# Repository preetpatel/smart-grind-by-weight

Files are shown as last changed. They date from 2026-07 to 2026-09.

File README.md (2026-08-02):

# Smart Grind-by-Weight

> **This is a fork of [jaapp/smart-grind-by-weight](https://github.com/jaapp/smart-grind-by-weight).**
> The original hardware design, firmware, and grinding algorithm are the work of **[Jaap (@jaapp)](https://github.com/jaapp)**.
> This fork is maintained by [@preetpatel](https://github.com/preetpatel) and has diverged since February 2026 —
> see [What's different in this fork](#-whats-different-in-this-fork).
> **Issues and support for this fork belong here, not upstream.**

**Turn any grinder into a precision smart grind-by-weight system**

<table>
<tr>
<td width="50%">

https://github.com/user-attachments/assets/e20ce3e2-417e-4a3b-bb48-05591fce9418

</td>
<td width="50%">

[Smart Grind-by-Weight Modification](media/smart-grind-by-weight-render.PNG)

</td>
</tr>
</table>

> **⚠️ Experimental Mod - Buyer Beware!**
> This is a **grinder modification project** that requires technical skill to build and may have rough edges. **Build at your own risk!**

The Smart Grind-by-Weight is a user-friendly, touch interface-driven, highly accurate open source grinder modification that transforms any grinder (with an accessible motor relay) into an intelligent grind-by-weight system. It was originally developed by Jaap for the Eureka Mignon Specialita, and can be adapted for other grinders.

**The concept is simple:** Perform a "brain swap" on your grinder. Replace the original controller with an ESP32-S3 controller and add a precision load cell to the mix.

**Upgrade cost:** €30-40 in parts
**Target accuracy:** ±0.03g tolerance
**No regrets:** No permanent modifications, and original grind-by-time mode is also available

---

## ✨ Features

- **User-friendly interface** with 3 profiles: Single, Double, Custom
- **Beautiful display** with simple graphics or detailed charts (easily switchable)
- **High accuracy**: ±0.03g error tolerance
- **Zero-shot learning**: Algorithm adapts instantly to any grind size, bean setting, humidity etc. without manual tuning
- **Original timed run preserved** – there is a setting to enable the original Grind-By-Time mode
- **BLE OTA updates** for firmware
- **Advanced analytics** — full in-browser dashboard over Web Bluetooth, plus local Streamlit tooling
- **On-device diagnostics** for calibration, load cell wiring, and mechanical instability faults
- **For Eureka**: No permanent modifications needed - just swap the screen and add 3D printed parts

---

## 🧠 Intelligent Grinding Algorithm

The predictive grinding system uses a zero-shot learning approach that adapts to any conditions:

```mermaid
flowchart LR
  start((Start Grind)) --> T[TARING]
  T --> E[PREDICTIVE<br/>learn latency & flow_rate<br/>compute motor_stop_target_weight]
  E --> S[SETTLING]
  S --> P[PULSE<br/>bounded pulse using effective_flow_rate]
  P -->|abs_error <= tolerance OR error < 0 OR pulses >= max| C[COMPLETED]
  P -->|needs more| S
```

**Key Innovation:** The algorithm learns grind latency and flow rate in real-time, then uses predictive control to stop just before the target weight, followed by precision pulses to reach exact accuracy. No manual tuning required.

---

## 🔀 What's different in this fork

This fork tracks upstream's hardware design and core algorithm, and adds reliability, diagnostics, and tooling work:

**Accuracy & motor control**
- Exact, deterministic motor pulses; pulse completion detected without polling the RMT driver
- 0.1s minimum pulse floor and preserved flow/calibration accuracy across grinds
- Tare and calibration failures now surface to the user instead of failing silently
- Correct auto-tune cancellation and failure reporting

**Diagnostics & device health**
- `LOAD_CELL_SATURATED` detection — catches A+/A- load cell wiring faults and blocks weight-mode grinds
- Internal and PSRAM heap census at startup and in the heartbeat, reported over BLE
- Per-task stack headroom in task heartbeats
- `grinder.py analyze` pulls grind data, system info, and diagnostics over one BLE connection into a **Device Health** dashboard view

**Grinding UX**
- Post-completion top-up pulses in **weight** mode (previously time mode only), with live weight and arc updates

**Stability & performance**
- BLE stack survives Bluetooth toggles instead of wedging
- LVGL heap allocated from PSRAM rather than internal DRAM; reduced per-frame heap churn and a fixed style leak
- LVGL pinned to 9.3.0 to match `lv_conf.h`

**Tooling & hardware**
- Host-side C++ regression tests, run by the build tool and in CI
- Forward-shifted cup holder variant for 43 mm cup bases

Full history is in the [commit log](https://github.com/preetpatel/smart-grind-by-weight/commits/main) and [Releases](https://github.com/preetpatel/smart-grind-by-weight/releases).

---

## 🚀 Quick Start

### For Users - Using Pre-built Firmware

1. **Get the parts** - ESP32-S3 AMOLED display + HX711 + load cell (~€35 total) → See [Parts List](docs/DOC.md#-parts-list)
2. **3D print the mounting parts** - All STL files included, no supports needed → See [3D Printed Parts](docs/DOC.md#3d-printed-parts) | [Community Designs](docs/3D_PRINTS.md)
3. **Flash firmware & calibrate** - [Web Flasher](https://coffeegrinder.preetpatel.com) (Chrome/Edge desktop + Android only) or command line
4. **Follow the assembly video** - [Complete Eureka build process](https://youtu.be/-kfKjiwJsGM) (by Jaap, for the original build)

**Ready to build?** → See **[DOC.md](docs/DOC.md)** for complete build instructions, parts list, and usage guide.

---

### For Developers - Building from Source

If you want to modify the code or contribute, see **[DEVELOPMENT.md](docs/DEVELOPMENT.md)** for build instructions.

**Design Files:** The complete Fusion 360 design is available at `3d_files/smart-grind-by-weight. Eureka Mignon.f3z` for modification and adaptation to other grinder models.

---

## 📊 Analytics Dashboard

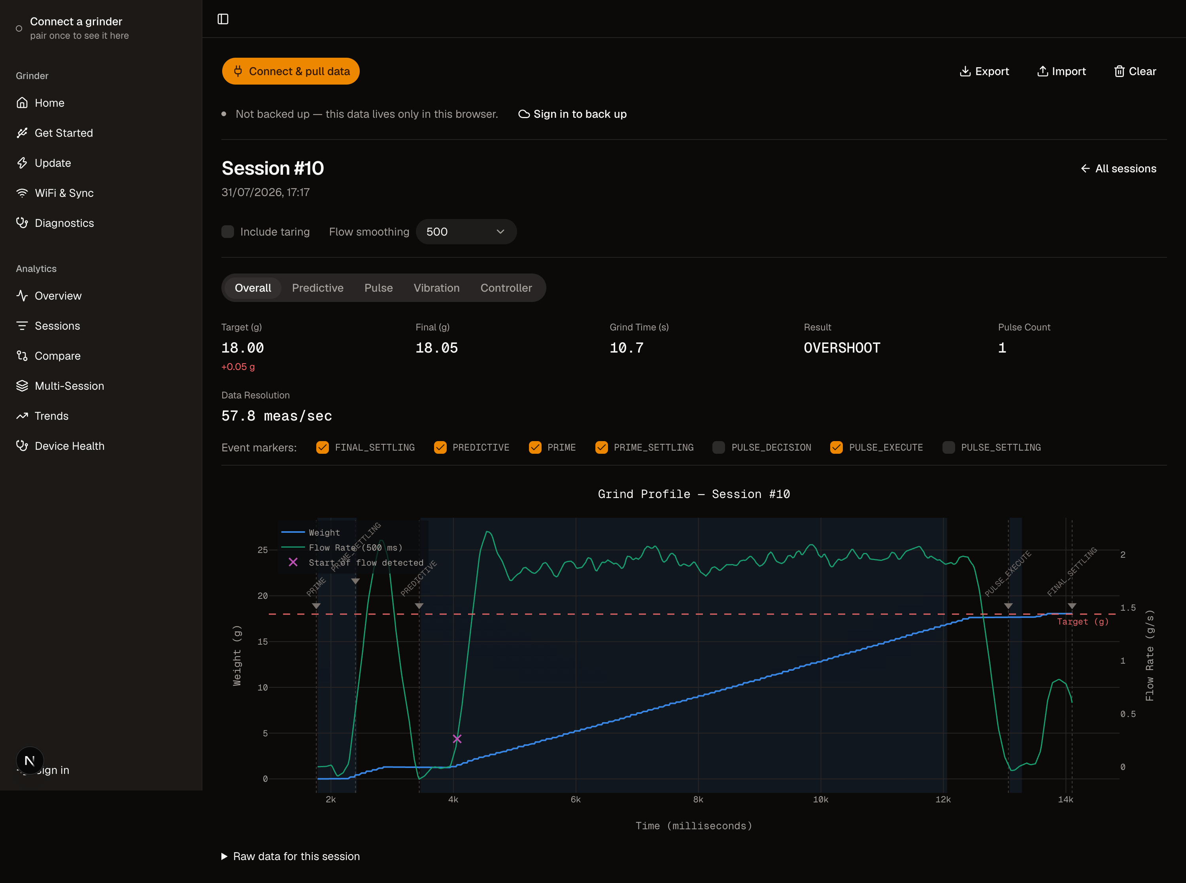
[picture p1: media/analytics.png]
Analytics Dashboard — single-session analysis
[](media/analytics.png)

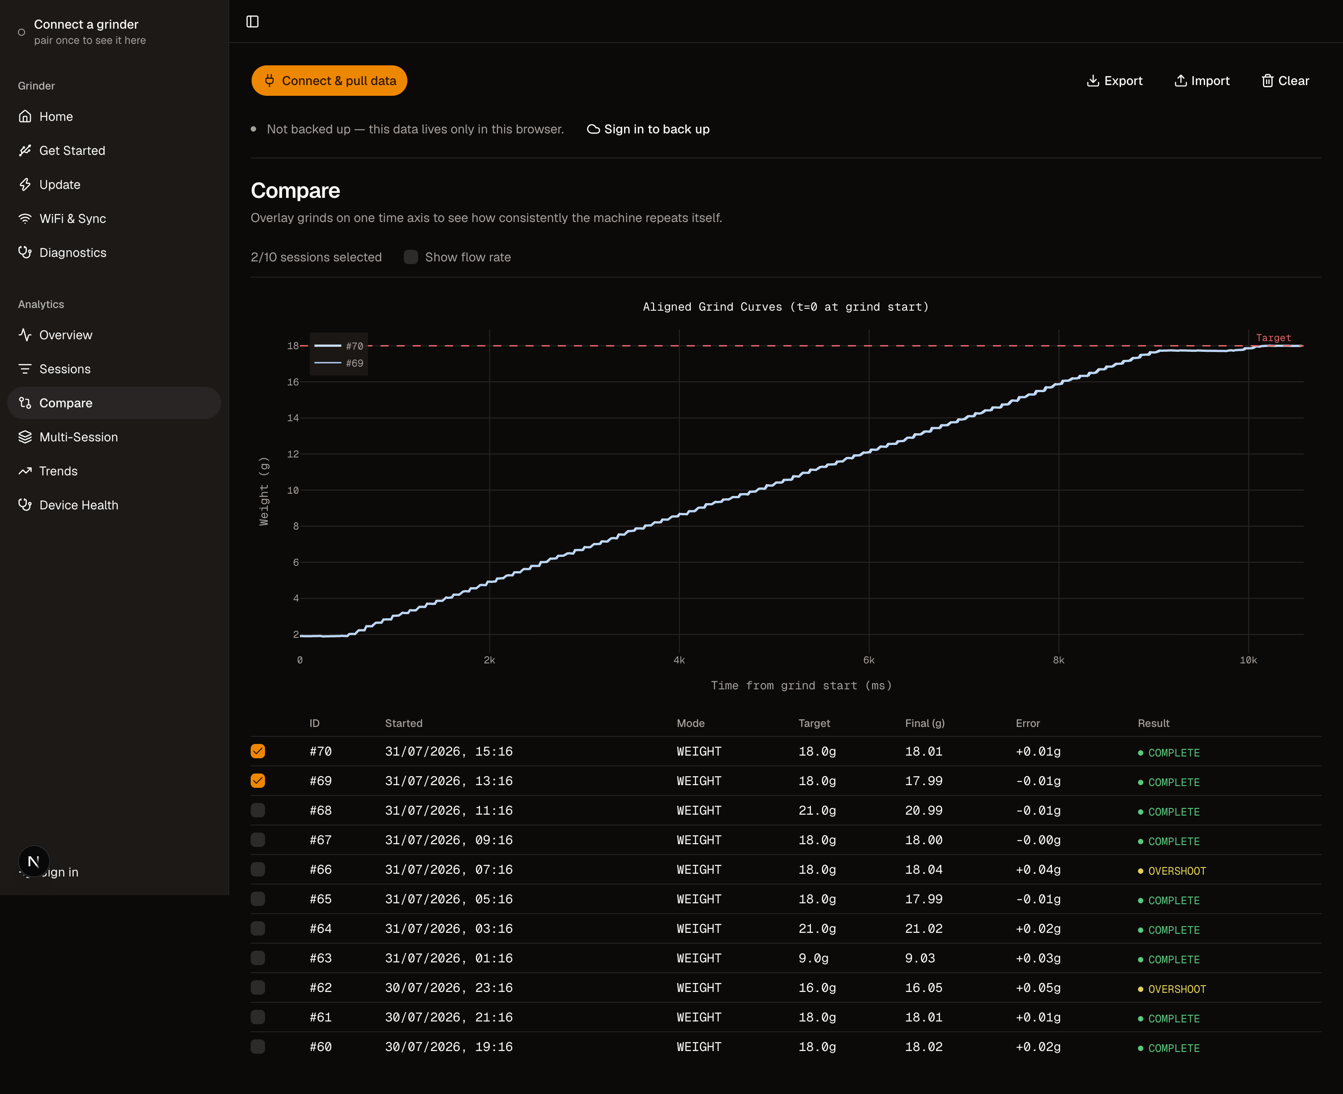
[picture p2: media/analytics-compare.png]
Aligned session comparison
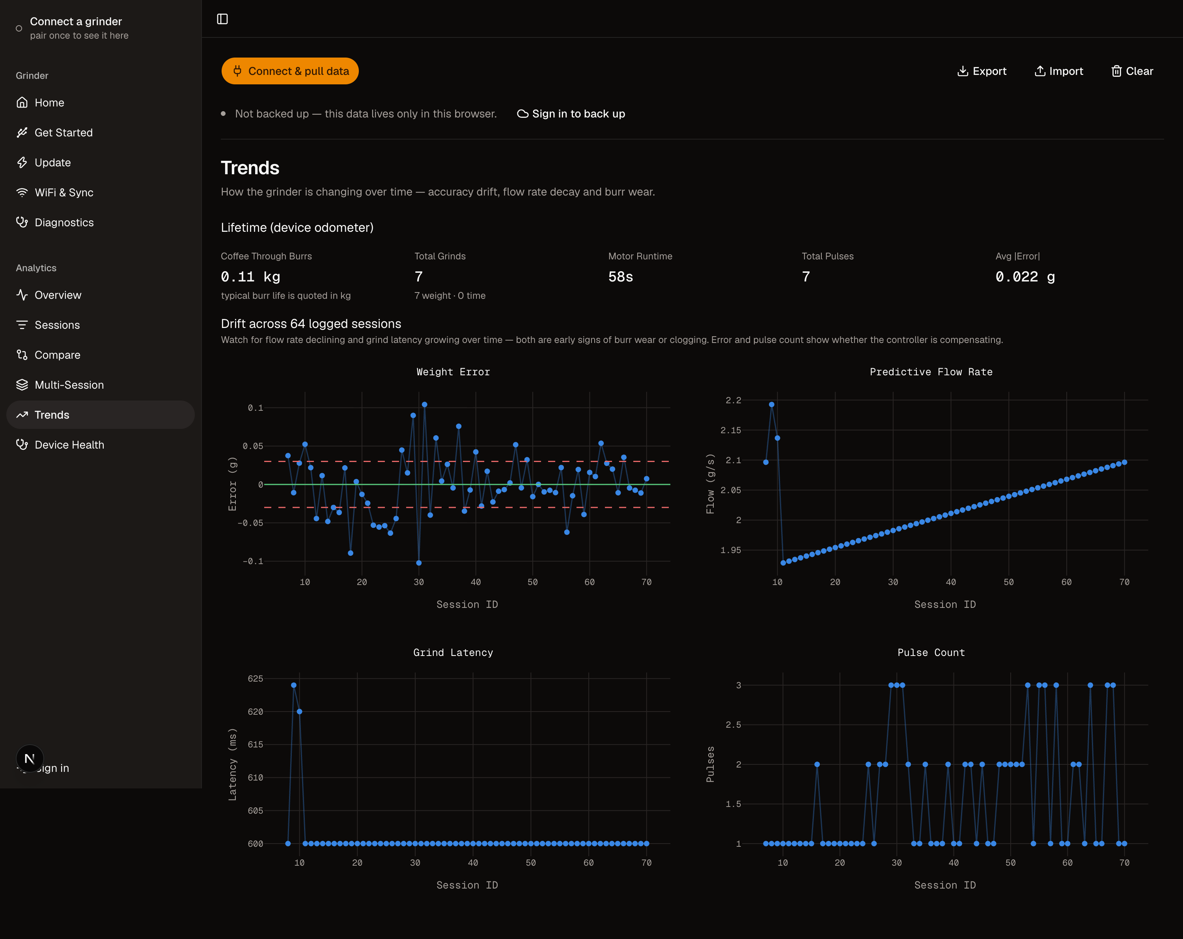
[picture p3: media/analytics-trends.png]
Long-term trends with burr-wear odometer
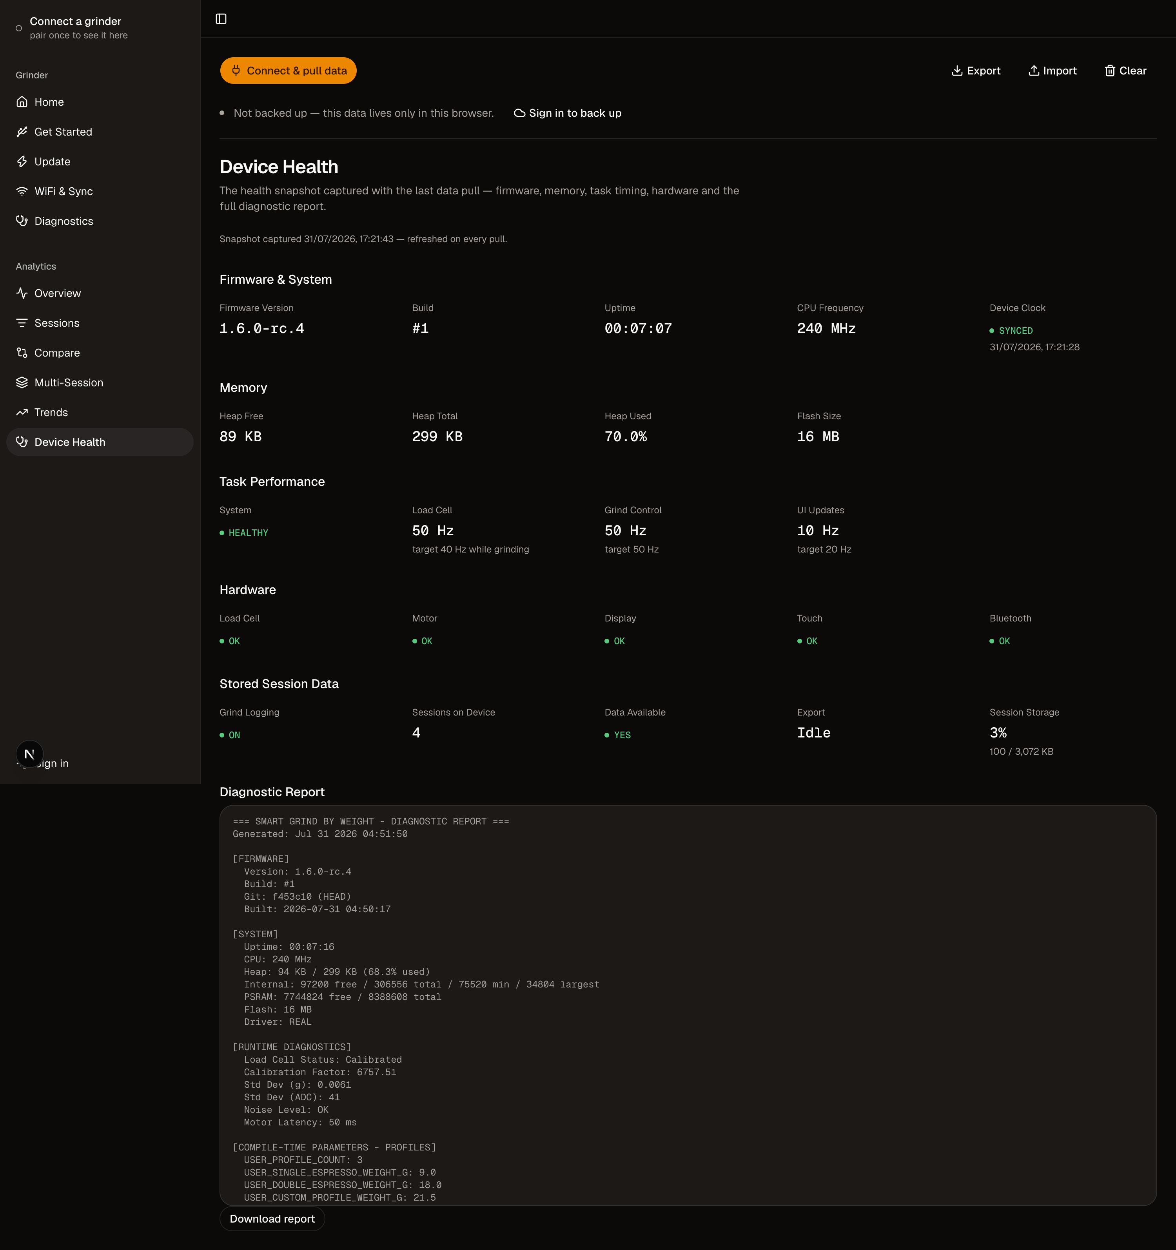
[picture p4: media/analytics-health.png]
Device health snapshot
[](media/analytics-compare.png) [](media/analytics-trends.png) [](media/analytics-health.png)

Pull everything from the grinder over one BLE connection — grind data, system info, and the diagnostics report — and analyze it right in your browser: the [Web Flasher](https://coffeegrinder.preetpatel.com)'s **Analytics** tab connects over Web Bluetooth (Chrome/Edge), no local tools needed. Single-session phase charts, vibration/FFT analysis, session-overlay comparison, multi-session statistics, long-term trends with a burr-wear odometer, and a Device Health view, with JSON export/import for sharing datasets.

Prefer working locally? The same pull and dashboard are available via the Streamlit tooling:

```bash
python3 tools/grinder.py analyze
```

Track accuracy, flow rates, grind times, and optimize your coffee workflow with detailed session analytics. The dashboard's **Health** view shows the firmware, memory, task performance, and diagnostics snapshot captured during the pull.

---

## 🙏 Attribution & Credits

**This project is a fork.** Nearly all of the hardware design, the mechanical parts, the predictive grinding algorithm, the LVGL interface, and the original firmware were built by **[Jaap (@jaapp)](https://github.com/jaapp)** in [jaapp/smart-grind-by-weight](https://github.com/jaapp/smart-grind-by-weight). If this project is useful to you, that's largely his work — please star the upstream repo.

On releasing the original project, Jaap wrote:

> My goal with this project was to get real-life experience coding with AI agents. The code reflects that learning journey. [...] "Vibe coding" with AI is great for POCs and testing theories. But afterward you must pivot and reimplement features while keeping a close eye on the architecture the AI produces. Otherwise you'll get stuck at dead ends that require painful refactoring.
>
> I'm very happy with the end result and I'm releasing the project as is. It eliminates grind weight variability from the espresso equation, bringing you one step closer to dialing in perfect shots.

Jaap has noted he has **limited availability for support** on the original project. Please don't file this fork's issues upstream — use [this repo's issue tracker](https://github.com/preetpatel/smart-grind-by-weight/issues).

The original project was in turn inspired by and builds upon:

- **[openGBW](https://github.com/jb-xyz/openGBW)** by jb-xyz - Open source grind-by-weight system
- **[Coffee Grinder Smart Scale](https://besson.co/projects/coffee-grinder-smart-scale)** by Besson - Smart scale integration concepts

Community 3D print designs are credited individually in [3D_PRINTS.md](docs/3D_PRINTS.md). Grinder compatibility reports link to upstream discussions, where that conversation lives.

---

## 📄 License

- **Software** — [GNU General Public License v3.0](LICENSE) or later
- **Hardware designs** — [CERN Open Hardware Licence v2 - Strongly Reciprocal](LICENSE) (CERN-OHL-S v2)

This fork is a modified version of the original work and is distributed under the same terms. Copyright is held jointly by the original Grind-by-Weight contributors and the contributors to this fork — see [LICENSE](LICENSE) for full terms and third-party component licenses.

---

## 📌 Project Status

This fork is maintained on a best-effort basis alongside a day job. It is shared **as-is** — expect limited support, and understand that this is an experimental modification to a mains-powered appliance that you are building and installing at your own risk.

**Want to dive deeper?** → Check out **[DOC.md](docs/DOC.md)** for comprehensive documentation.

**Different grinder?** → See **[Grinder Compatibility Matrix](docs/GRINDER_COMPATIBILITY.md)** for adaptation guidance.

**Having issues?** → See **[TROUBLESHOOTING.md](docs/TROUBLESHOOTING.md)** for common problems and solutions.

**Changelog & Updates** → See **[Releases](https://github.com/preetpatel/smart-grind-by-weight/releases)** for version history and updates.

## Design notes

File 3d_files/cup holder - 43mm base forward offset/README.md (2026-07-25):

# Cup holder — 43 mm base, shifted 8 mm forward

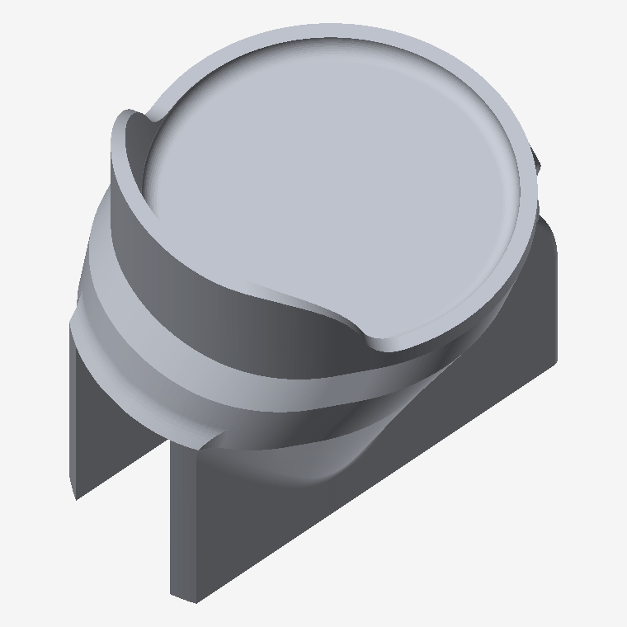
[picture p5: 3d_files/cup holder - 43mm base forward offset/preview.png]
preview


A re-cut of the dosing-cup cradle that moves the cup **8 mm forward** (toward the
screw holes) and optionally tightens the base pocket to suit a **43 mm** cup base.

## Why

On my grinder the cup sits far enough back that it touches the rear wall of the
grinder body. That contact loads the cup against something other than the scale
and shows up as noise on the load cell. Moving the cup forward removes the
contact, and as a side effect shortens the moment arm from the screw line to the
cup axis (22.75 mm → 14.75 mm), which also helps the reading settle.

## ⚠️ This is not derived from `3d_files/58mm Cup holder.stl`

The baseline here is my own STEP export from the project's Fusion design
(`PRODUCT('smart-grind-by-weight. Eureka Mignon')`), and it is **a different part**
from the `58mm Cup holder.stl` committed at the top level of `3d_files/`:

| | `58mm Cup holder.stl` | baseline used here |
| --- | --- | --- |
| volume | 26.77 cm³ | 40.67 cm³ |
| size (X×Y×Z) | 49.00 × 56.20 × 38.70 | 49.33 × 59.41 × 55.97 |
| mount | screw tab on the side | bottom plate, 2× Ø4.0 counterbored from below |
| backstop | none | saddle-shaped, +Y side |

So treat these files as a **new variant**, not a drop-in replacement. The exact
baseline is committed under `source/` so the result is reproducible.

## Files

| file | pocket Ø | fit on a 43.0 mm base | ledge OD | max width | volume |
| ---- | --- | --- | --- | --- | --- |
| `Cup holder - 43mm base, 8mm forward.stl` | 43.500 | 0.25 mm/side, seats on the fillet ring 1.03 mm above the floor | 47.500 | 48.14 | 39.80 cm³ |
| `Cup holder - 43mm base, 8mm forward (loose fit).stl` | 44.000 | 0.50 mm/side | 48.000 | 48.47 | 40.04 cm³ |
| `Cup holder - stock pocket, 8mm forward.stl` | 45.329 (unchanged) | 1.16 mm/side, drops to 0.18 mm above the floor | 49.328 (unchanged) | 49.33 | 40.67 cm³ |

**Start with the 43.50 file.** A 43 mm base already fits the stock 45.33 pocket,
but with 1.16 mm of play per side the cup can shift and rock — which is working
against the load cell. At 43.50 the base rests on the R2 fillet ring and
self-centres to 0.25 mm.

If it binds, use the 44.00 version. FDM holes typically come out 0.1–0.4 mm
undersize, so 0.25 mm/side is genuinely tight. The stock-pocket file is the
conservative option: forward shift only, pocket untouched.

## What is identical to the baseline

- **Screw holes.** Ø6.500 counterbores and Ø4.000 through-holes at
  (±3.5, −138.0000), verified bit-identical.
- **The whole mount.** All 11,295 baseline triangles lying fully below the
  z = −167 freeze line are present verbatim; mount plate, side rails and every
  mating face are untouched.
- **Overall height**, z = −197.5 … −141.53.
- **Backstop wall thickness and draft.** Inner and outer backstop faces both move
  by the same radial offset at every height, so the 2 mm wall and the 8.74° draft
  are preserved, not approximated.

## What changed

- Cup axis y = −115.25 → **−123.25** (8 mm toward the screws).
- Pocket Ø45.329 → **Ø43.500** (in the recommended file); floor Ø41.329 → Ø39.500.
- Rear-most point of the part −88.59 → −91.00, so the part itself also gains
  2.4 mm of clearance from the grinder wall while the cup gains the full 8 mm.

## Printing

Same orientation and settings as the stock cup holder. Two things to know:

- Unsupported downward-facing area (past 45°) goes **28.7% → 32.2%** in the
  z −172…−140 band, from the forward lean. That zone already needed support.
- The ramp from the mount to the cradle is deliberately **linear rather than
  smoothed**, which caps the new front flare at ~34° from vertical instead of
  ~52°. The tradeoff is faint tangent creases at z = −167 and z = −157; they are
  cosmetic.

All three meshes are watertight: 87,890 triangles, 0 non-manifold edges,
0 degenerate triangles.

## Regenerating

`remodel.py` needs only numpy and reads `source/Cup holder (baseline export).stl`:

```bash
python3 remodel.py 43.5 8.0 "Cup holder - 43mm base, 8mm forward.stl"
python3 remodel.py <pocket_dia_mm> <forward_shift_mm> <output.stl>
```

It prints the resulting pocket diameter, the cup-axis position, where a flat base
will seat, watertightness checks and the before/after bounding box. Tune
`Z_RAMP_LO` / `Z_RAMP_HI` at the top of the file to move the blend band.

### How it works

The cradle-to-pedestal transition in the STEP is 26 B-spline blend surfaces, so
editing the STEP directly would break tangency, and rebuilding the saddle-shaped
backstop from scratch loses fidelity. Instead the cradle is offset **radially**
about the cup axis and then translated, because a constant radial offset maps
every analytic feature of the cradle exactly:

```
cylinder  r -> r + dr          cone   r -> r + dr  (at constant z)
torus     R -> R + dr          planes unchanged
```

The offset is ramped to zero between z = −157 and z = −167, so the mount below is
untouched. The mesh is conformally refined first — split decisions are made per
*edge*, so adjacent triangles always agree and no cracks or T-junctions appear —
and edges at or below the freeze line are never re-tessellated, which is what
keeps the mount bit-identical.

Because the map preserves z and is monotone in radius, it is injective on every
z-slice and therefore cannot fold the surface onto itself.

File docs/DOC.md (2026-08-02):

# Smart Grind-by-Weight Documentation

Complete build instructions, parts list, and usage guide for the Smart Grind-by-Weight system.

---

## 📋 Table of Contents

- [Smart Grind-by-Weight Documentation](#smart-grind-by-weight-documentation)
  - [📋 Table of Contents](#-table-of-contents)
  - [🛠️ Parts List](#️-parts-list)
    - [3D Printed Parts](#3d-printed-parts)
    - [Fusion 360 Source Files](#fusion-360-source-files)
  - [📹 Assembly Video](#-assembly-video)
  - [🔌 Installation \& Wiring](#-installation--wiring)
    - [Pin Configuration](#pin-configuration)
    - [Recommended Wire Lengths](#recommended-wire-lengths)
    - [Installation Steps](#installation-steps)
  - [🚀 Firmware Installation](#-firmware-installation)
    - [🌐 Web Flasher (Recommended)](#-web-flasher-recommended)
    - [Command Line (Fallback)](#command-line-fallback)
  - [⚖️ Initial Calibration](#️-initial-calibration)
    - [Auto-Tune Motor Response](#auto-tune-motor-response)
    - [Diagnostics System](#diagnostics-system)
  - [📱 Usage Guide](#-usage-guide)
    - [Grinding Profiles](#grinding-profiles)
    - [Navigation](#navigation)
    - [Grind Settings](#grind-settings)
    - [Basic Operation](#basic-operation)
    - [Quick Scale View](#quick-scale-view)
    - [Display Modes](#display-modes)
    - [Idle Clock Face](#idle-clock-face)
  - [🗺️ User Interface Navigation](#️-user-interface-navigation)
  - [⚡ Automated Grind Flow](#-automated-grind-flow)
  - [🔵 Bluetooth Connectivity](#-bluetooth-connectivity)
  - [🔍 Diagnostic Report](#-diagnostic-report)
    - [Report Contents](#report-contents)
    - [Access Methods](#access-methods)
  - [📊 Analytics \& Data Export](#-analytics--data-export)
    - [Launch Interactive Dashboard](#launch-interactive-dashboard)
    - [Available Tools](#available-tools)
    - [Tools Directory Structure](#tools-directory-structure)
  - [🧠 Algorithm Details](#-algorithm-details)
    - [Grinding Algorithm](#grinding-algorithm)
  - [❓ Frequently Asked Questions](#-frequently-asked-questions)
  - [🔧 Troubleshooting](#-troubleshooting)

---
## 🛠️ Parts List

> **Note:** All links are **for reference only** — sellers and items are **not personally verified** unless explicitly stated.

- **[Waveshare ESP32-S3 1.64" AMOLED Touch Display](https://www.waveshare.com/esp32-s3-touch-amoled-1.64.htm)** — Main controller
- **[HX711 ADC module](https://nl.aliexpress.com/item/1005006851380544.html)** — Load cell amplifier
- **MAVIN or T70 load cell** (0.3 – 1 kg range) — Weight sensor
  ⚠️ Avoid cheap unshielded small load cells — accuracy will suffer
  - **Required dimensions:** 70 × 22 × 15 mm (L × H × D)
  - **Screw pattern:** 4 holes in rectangular layout (`: :` pattern), NOT linear (`. . . .`)
  - **1 kg:** Recommended. Suits portafilter use cases.
  - **0.3 kg:** Only suitable for dosing cups.
  - **Examples:**
    - [AliExpress T70](https://nl.aliexpress.com/item/1005009409460619.html)
    - [TinyTronics MAVIN](https://www.tinytronics.nl/en/sensors/weight-pressure-force/load-cells/mavin-load-cell-0.3kg)
    - [NA6 (Mavin) 0.3 / 1 kg](https://www.alibaba.com/product-detail/subject_1601564701384.html) - [NA6 that delivers to Germany](https://de.aliexpress.com/item/1005002600322988.html)
    - [T70 1 kg](https://nl.aliexpress.com/item/1005008658337192.html)
    - [P70 1 kg](https://nl.aliexpress.com/item/1005006257978435.html) (looks compatible with T70, not personally tested)
  - **Tested:** Only the 1 kg T70 and 0.3 kg Mavin load cells have been personally verified
- **6× M3 screws** (≈10 mm) — Mounting hardware
- **1000 µF capacitor** (≥10 V) — Brownout protection. Smaller values may work; larger voltage ratings (e.g. 25V) are fine but physically bigger, so check fitment. [Example (untested)](https://nl.aliexpress.com/item/1005006037906723.html)
- **Wires & Dupont connectors** — General wiring  
  Example: [22 AWG silicone wire set](https://www.aliexpress.com/item/2255800441309579.html)
- **Dupont connector kit** — [Example (untested)](https://nl.aliexpress.com/item/1005008995345289.html)
- **Angled pin headers** — [Example (untested)](https://nl.aliexpress.com/item/1005006149080284.html)
- **[JST-PH 4-pin male connector (optional)](https://nl.aliexpress.com/item/1005009479983500.html)** — Optional solder-free connection to Eureka

[Wired Waveshare Board](../media/waveshare_board_wired_up_1.jpg)

### 3D Printed Parts

All parts designed to print **without supports**. Keep the orientation of the STL files. Some holes are covered with thin plastic layers that you can easily remove.

**Print Settings:**
- **Material**: PETG (preferred) - Flexible enough for snap fits to work properly
- **Layer Height**: 0.2mm
- **Alternative**: PLA might work but will offer a reduced experience due to brittleness

**Default Eureka Parts** (`3d_files/`):

- **[Screen adapter](../3d_files/Waveshare%20AMOLED%201_64%20adapter.stl)** - Mounts Waveshare screen to Eureka location
- **[Back plate](../3d_files/Back%20plate.stl)** - Mounts to Eureka and holds HX711/load cell
- **[Cover plate](../3d_files/Cover.stl)** - Clean finishing cover
- **Cup holder** - Connects to load cell for dosing cup
  - **[54mm cup holder](../3d_files/54mm%20Cup%20holder.stl)** - For 54mm dosing cups
  - **[58mm cup holder](../3d_files/58mm%20Cup%20holder.stl)** - For 58mm dosing cups
- **Screw hole covers** - Hides screws and protects against coffee grounds
  - **[54mm hole cover](../3d_files/54mm%20Cup%20holder%20hole%20cover.stl)**
  - **[58mm hole cover](../3d_files/58mm%20Cup%20holder%20hole%20cover.stl)**

**Community Designs:**

Looking for grinder-specific mounts or portafilter holders? See **[Community 3D Designs](3D_PRINTS.md)** for portafilter holders, alternative screen mounts, and adaptations for other grinder models.

### Fusion 360 Source Files
- **[All components](https://a360.co/3HYgubb)** - Customizable source files

Use these to adjust mounts for your specific grinder. Cup holders available for 54mm and 58mm dosing cups.
Compatible dosing cup: [AliExpress 54mm Cup](https://nl.aliexpress.com/item/1005006526852408.html)

---

## 📹 Assembly Video

Watch the complete Eureka Mignon Specialita assembly process: **[YouTube Assembly Guide](https://youtu.be/-kfKjiwJsGM)**

---

## 🔌 Installation & Wiring

[Wiring Diagram](../media/wiring_diagram.png)

### Pin Configuration

**HX711 Load Cell Amplifier Connections:**
```
ESP32-S3 GPIO 2    →    HX711 SCK
ESP32-S3 GPIO 3    →    HX711 DOUT
ESP32-S3 3.3V      →    HX711 VCC
ESP32-S3 GND       →    HX711 GND
```

**Load Cell to HX711 Wiring:**
```
Load Cell           HX711
Red (E+)         →  E+
Black (E-)       →  E-
White (A-)       →  A-
Green (A+)       →  A+
Yellow (Shield)  →  GND
```

- Connect the load cell shield wire (usually yellow) to the HX711 GND
- The HX711 only has 1 GND pin - solder the shield wire to the backside of the pin header
- **Tip**: Keep the load cell wire as short as possible to reduce noise

### Recommended Wire Lengths

Advised lengths:
- **Load cell → HX711:** ~10 cm
- **Eureka → Waveshare board:** ~15 cm (image shows a slightly shorter lead; 15 cm gives comfortable slack)
- **Grinder harness → HX711:** ~30 cm to route from the housing feed-through to the amplifier without strain

These lengths fit the Eureka Mignon layout shown here; other grinders may require different cable lengths.

[Wire Length Example](../media/wiring%20length.jpg)

**Eureka Mignon Connections:**

⚠️ **CRITICAL WARNING:** Always verify your specific Eureka's wiring independently! Wire colors vary between units and cannot be trusted. Use the numbered pin positions shown in the reference image.

Using the 4-pin Eureka plug pinout (see `../media/4-pin_Eureka_plug_pinout.png`), counting from left to right with the plug oriented with 'ribs' towards you:

[4-Pin Eureka Plug Pinout](../media/4-pin_Eureka_plug_pinout.png)

```
ESP32-S3 5V        →    Pin 1 (5V power)
                        Pin 2 (Button signal - not used in this project)
ESP32-S3 GPIO 18   →    Pin 3 (Motor control signal)
ESP32-S3 GND       →    Pin 4 (Ground)
```

**4-Pin Eureka Plug Reference (Left to Right):**
- **Pin 1**: 5V power supply
- **Pin 2**: Button signal (unused in this project)  
- **Pin 3**: Motor control signal *(active-high — the motor runs when GPIO 18 drives this pin to ~3.3V)*
- **Pin 4**: Ground

⚠️ **VERIFY 5V:** Use a multimeter to confirm 5V pin - wire colors vary between units! The Waveshare board has reverse polarity protection, and button/motor wires can be swapped without risk of damage.

### Installation Steps

1. **Flash the firmware** on the Waveshare board (see Firmware Instructions below)
2. **Add the 1000μF capacitor** between 5V and ground (protects against brownouts)
3. **Create HX711 to Waveshare connection:**
   - Add angled pin headers to HX711 (VCC, GND, DOUT, SCK pins)
   - Connect dupont cables to Waveshare board
   - Load cell can be directly soldered to HX711 (Make the wires as short as possible. Connect shield wire as well to GND)
4. **For Eureka Mignon assembly:**
   - Disassemble top plate and front plate
   - Remove the button: unscrew from front plate, open grinder from below, unplug connector from powerboard, store plug+cable to revert mod later
   - Use JST-PH plug to connect to Waveshare board
   - **WARNING:** Wire colors vary significantly between Eureka units - always verify pin functions with a multimeter before connecting!
   - Mount Waveshare screen using 3D printed adapter where original screen was (the Waveshare screen with adapter replaces the original screen and reuses the original mounting screws)
   - Fish HX711 wire through housing, exit via button hole
   - Mount load cell and HX711 to 3D printed back plate
   - Clip 3D printed back plate onto Eureka Mignon
   - Connect plug to HX711
   - Add 3D printed cover plate and screw down
   - Add 3D printed dosing cup holder on load cell and screw down
   - Hide screws with 3D printed screw covers
5. **Calibrate load cell** (see [Initial Calibration](#️-initial-calibration)) 

---

## 🚀 Firmware Installation

### 🌐 Web Flasher (Recommended)
**[🔗 Open Web Flasher Tool](https://coffeegrinder.preetpatel.com)**

**Browser Compatibility:**
- ✅ **Chrome** (Desktop & Android) - Full support
- ✅ **Microsoft Edge** (Desktop) - Full support
- ❌ **Safari/iOS** - Not supported (use command line method below)
- ❌ **Firefox** - Not supported (use command line method below)

**Two-Step Installation Process:**

1. **First Install (Grinder → Install, USB - One Time Only)**
   - Connect ESP32 via USB cable
   - Use Chrome/Edge browser (desktop or Android)
   - Select firmware version from dropdown
   - Click "Flash via USB" - opens ESP Web Tools
   - After installation, device is ready for wireless updates

2. **Future Updates (My Grinder → Update, BLE - After Installation)**
   - Power on the grinder (Bluetooth is on by default and stays on)
   - Select firmware version from the Update dropdown
   - Click "Connect & Flash Firmware"
   - Update happens wirelessly - **no USB cable needed**

**Key Benefits:**
- ✅ **No downloads needed** - firmware hosted automatically
- ✅ **No command line** - simple web interface
- ✅ **Automatic version listing** - all releases available in dropdown
- ✅ **Wireless updates** - once installed, never need USB again

*Initial USB flashing powered by [ESP Web Tools](https://esphome.github.io/esp-web-tools/)*

### Command Line (Fallback)
```bash
# First time (USB) - if web flasher unavailable
python3 tools/grinder.py upload smart-grind-by-weight-vX.X.X.bin

# Updates (BLE) - device advertises whenever it is powered on
python3 tools/grinder.py upload smart-grind-by-weight-vX.X.X.bin
```

**Manual firmware download:** [Releases page](https://github.com/preetpatel/smart-grind-by-weight/releases)  
**Build from source:** See [DEVELOPMENT.md](DEVELOPMENT.md)

---

## ⚖️ Initial Calibration

After flashing firmware, calibrate the load cell for accurate measurements:

1. **Access calibration**: Menu → Calibrate (Tools section)
2. **Empty calibration**: Remove all weight from scale platform → Press OK
3. **Weight calibration**: 
   - Place known weight on scale (e.g., coffee mug with water)
   - Use +/- buttons to adjust displayed value to match actual weight
   - Press OK to complete

**Tip**: A coffee mug with water makes ideal calibration weight - weigh it on kitchen scale first.

### Auto-Tune Motor Response

The auto-tune feature models your grinder's motor response behavior by measuring the physical lag between relay activation and grounds production. This accounts for hardware variations like voltage differences (110V vs 220V), relay types (solid-state vs mechanical), and burr inertia across different grinder models. The default 50ms value works well for most setups, but if you experience unreliable pulse corrections or want to minimize coffee waste through hardware-specific optimization, run auto-tune via **Menu → Tune Pulses** (Tools section). The 1-2 minute calibration process finds the minimum reliable pulse duration for your specific hardware and saves it automatically.

### Diagnostics System

The system includes comprehensive load cell health monitoring accessible via **Menu → Diagnostics**. A warning icon (⚠) appears in the top-right corner when diagnostics are active - tap it to navigate directly to the diagnostics page.

**Diagnostic Types:**
1. **Load Cell Not Calibrated** - Appears until calibration is completed via Menu → Calibrate (Tools section)
2. **Sustained Noise** - Triggers after 60 seconds of excessive noise; clears after 120 seconds of acceptable levels
3. **Mechanical Instability** - Detects sudden weight drops during grinding (3+ events); auto-resets on next grind or via manual reset
4. **Load Cell Saturated** - Raw ADC reading pegged at a rail (0x000000/0xFFFFFF) for 10+ consecutive samples; indicates a load cell signal wiring fault (broken or miswired A+/A- wires). While active, weight-mode grinds are refused because there is no usable weight feedback; time mode still works. Clears automatically once healthy readings return

**Displayed Values:**
- **Motor Latency** - Current motor response latency in milliseconds (default: 50ms, or calibrated value from auto-tune)
- **Calibration Factor** - Load cell calibration factor from Menu → Calibrate (Tools section)

**Noise Floor Diagnostics:**

Access via **Menu → Diagnostics → Noise Floor**. These readings tell you how much a resting scale
wanders, which is what determines how many decimal places the weight display can honestly show and
how reliably pulse corrections can land.

Two separate series are reported. **Sample** describes a single raw ADC reading — the sensor's
intrinsic noise. **Display** describes the smoothed series the UI is actually built from, which is
what you would see move on screen.

| Value | Meaning |
|---|---|
| **Resolution** | Weight of one ADC count. The hard quantisation floor — no amount of filtering gets below it |
| **Sample rate** | Observed ADC rate. Should sit near 10 SPS; a very different number means the HX711 RATE pin is strapped wrong |
| **Sample sigma** | Standard deviation of single readings over 5 s |
| **Sample (ADC)** | The same figure in raw counts, useful when comparing setups before calibration |
| **Sample p-p** | Largest peak-to-peak excursion over the last 30 s. Catches intermittent spikes that a standard deviation averages away |
| **Display sigma** | Standard deviation of the smoothed series over 30 s |
| **Display p-p** | Peak-to-peak of the smoothed series over 30 s |
| **0.01g spread** | How many 0.01 g steps the display noise spans. **1 step** (green) means a hundredths digit would hold still; 2–3 (orange) means it would twitch; more (red) means that digit would show nothing but noise |
| **Noise level** | Whether noise is bad enough to cause slow taring (>2 s) or timeouts |

**Run 30s Noise Test** freezes a clean capture. Press it, then leave the scale completely
undisturbed for 30 seconds — the result is held on screen afterwards so you can pick the machine
back up and still read it. The same figures are also written to the BLE debug log, so
`python3 tools/grinder.py debug` will capture them for a bug report.

**Important:** Noise readings in grams require prior calibration, since they are derived from the
calibration factor. High readings indicate wiring issues — check the shield connection and use
shorter load cell leads. Run the test in a stable, vibration-free environment with a cup on the
scale and hands off.

---

## 📱 Usage Guide

### Grinding Profiles
All profiles are fully customizable. Default grind-by-weight targets (fallback time values shown in parenthesis):
- **Single**: 9 g (5 s)
- **Double**: 18 g (10 s)  
- **Custom**: 21.5 g (12 s)

> 💡 **Tip** – the target label always shows the active unit (`g` or `s`). Long-press to edit in whichever mode you are currently using. Targets clamp to 5–1000 g in weight mode and 0.1–25 s in time mode.
>
> ⚠️ A 0.1 s timed profile is not as repeatable as a 0.1 s top-up pulse. Timed grinds run the motor continuously and stop when the 20 ms control loop notices the target has elapsed (±20 ms, i.e. ±20 % at 100 ms) with no compensation for motor start-up lag, whereas the "+" pulse on the completion screen is timed exactly in hardware. For tiny doses, prefer the pulse.

### Navigation
- **Swipe left/right** to navigate between menu tabs
- **Swipe up/down** on the ready screen to toggle between grind-by-weight and grind-by-time modes (when enabled in Menu → Grind Settings)
- **Tap** to select profiles or buttons
- **Long press** on profile targets to edit/customize them

> **Color cues:** The GRIND button background turns **red** in weight mode and **blue** in time mode, so you always know which behaviour is armed.

### Grind Settings
Access **Menu → Grind Settings** to configure:
- **Swipe Gestures**: Enable/disable vertical swipe gestures for mode switching (default: disabled)
- **Time Mode**: Directly toggle between Weight and Time modes regardless of swipe setting
- **Start on Cup**: Start the active profile automatically when the scale gains ≈50 g within ~2 s (after a short post-boot warmup)
- **Return on Removal**: Leave the completion screen as soon as that cup weight drops back off the scale
- **Purging** *(Advanced)*: Control how the grinder saturates itself before weight-mode grinding
  - **Prime mode**: Keeps the coffee used to saturate the grinder, continues immediately
  - **Purge mode** (default): Prompts you to discard stale grinds before continuing
  - **Amount slider**: Configure purge/prime amount (0.1g-5.0g, default 1.0g). The stop point is coast-compensated (grounds keep arriving ~300ms after motor-off), so the configured amount is approximately what actually lands.
  - **"Keep purge grinds from now on" checkbox**: Appears during purge confirmation (checked by default) - switches to Prime mode when left checked; uncheck it to stay in Purge mode

  *Explanation:* The time between motor start and grinds hitting the cup (grind latency) is used to predict the coast time (how long grinds will keep coming after the motor is disengaged). Purging clears stale coffee and saturates the grinder with fresh grounds, ensuring accurate latency detection. If you prefer to keep all coffee without manual intervention, select Prime mode.

### Basic Operation
These steps describe the default grind-by-weight workflow:
1. Select profile by tapping on the main screen
2. Long press the profile target to edit/customize the weight if needed
3. Place the dosing cup on the scale platform
4. Press the GRIND button – the scale will tare automatically
5. The system grinds to the precise target weight using the predictive algorithm
6. GRIND COMPLETE shows the final settled weight in grams (with statistics)

> Optional automation (Menu → Grind Settings): enable the new auto-start toggle to begin grinding as soon as the scale sees ~50 g arrive (no tare needed); the system waits for the load cell to gather enough quiet samples before arming itself, then auto-return jumps back to Ready whenever that cup is lifted off again.

Need the stock timed run? Enable swipe gestures in **Menu → Grind Settings**, then swipe up or down on the ready screen before you start; the GRIND button background turns blue to confirm time mode is active (red = weight). Alternatively, use the direct **Time Mode** toggle in the menu.

> **Top-up pulse button:** On the GRIND COMPLETE screen a "+" button appears next to OK in both weight and time mode. Each tap fires a fixed 100ms motor pulse (roughly 0.1–0.2 g) with no re-tare and no purge, so an 17.8 g shot can be nudged to 18.0 g. The weight on screen counts up live as the grounds land, and the button greys out until that pulse has settled — tap it again to add more.

### Quick Scale View
Need a simple live readout? Open **Menu → Scale** to jump into a full-screen weight display. Entering the page automatically tares the scale (using the same blocking overlay as the main workflow), and a large `TARE` button at the bottom lets you re-zero manually whenever you need.

### Display Modes
- **Arc Layout**: Clean, minimal arc-based interface
- **Nerdy Layout**: Detailed charts showing flow rates and real-time grinding analytics
- **Switching**: Tap anywhere on grind screen to switch between layouts during grinding

### Idle Clock Face
Left alone for five minutes, the grinder turns into a clock: the screen fills with the current time so it is readable from across the kitchen. Five minutes after that the backlight drops to the screensaver level and the clock stays put.

Touching the screen brings the normal UI straight back, and so does the slightest load on the scale — setting a cup down wakes it before you have finished putting it down, and **Start on Cup** still fires on that same placement if you have it enabled. The waking tap is swallowed by the clock face, so it can never trigger the button underneath it.

The face only appears once the clock has actually been set (by a Bluetooth client connecting, or over WiFi via SNTP) — an unsynced grinder just dims at five minutes as it always did. Turn it off entirely with **Menu → Display → Clock Face**.

---

## 🗺️ User Interface Navigation

```
Main Screen (swipe left/right between tabs, up/down to toggle weight/time mode if enabled)
|
+-- Single Profile 
|   |-- Weight display (long press to edit)
|   \-- GRIND button (red=weight, blue=time)
|
+-- Double Profile
|   |-- Weight display (long press to edit)
|   \-- GRIND button (red=weight, blue=time)
|
+-- Custom Profile
|   |-- Weight display (long press to edit)
|   \-- GRIND button (red=weight, blue=time)
|   \-- Grind completion (both modes): OK + PULSE buttons
|
\-- Menu (scrollable hub)
    |
    +-- Tools (quick actions)
    |   |-- Scale (live weight view with Tare action)
    |   |-- Calibrate (launch calibration workflow)
    |   |-- Tune Pulses (auto-tune motor latency)
    |   \-- Motor Test (1s safety pulse)
    |
    +-- Settings
    |   +-- Bluetooth
    |   |   |-- Bluetooth toggle (stays on until turned off)
    |   |   |-- Bluetooth startup toggle (auto-enable at boot, default on)
    |   |   \-- Connection status display
    |   |
    |   +-- Display
    |   |   |-- Normal brightness slider
    |   |   |-- Screensaver brightness slider
    |   |   |-- 24-Hour clock toggle (off = AM/PM, the default)
    |   |   \-- Clock Face toggle (idle screen becomes a clock, default on)
    |   |
    |   \-- Grind Settings
    |       |-- Swipe Gestures toggle (enable/disable vertical swipes)
    |       |-- Time Mode toggle (direct weight/time mode selection)
    |       |-- Start on Cup toggle (start when ≈50 g arrives within ~2 s)
    |       |-- Return on Removal toggle (drop back to Ready when that weight leaves)
    |       |-- Purging (Prime/Purge radio buttons)
    |       \-- Amount slider (0.1g-5.0g for purge/prime operation)
    |
    \-- Info
        +-- Diagnostics
        |   |-- Load Cell Status (calibration flag, calibration factor)
        |   |-- Noise Floor (std dev g/ADC, noise level indicator)
        |   |-- Active diagnostic warnings
        |   \-- Reset diagnostics button
        |
        +-- System Info
        |   |-- Firmware version & build number
        |   |-- Real-time weight sensor data (instant, samples, raw)
        |   |-- Uptime display
        |   \-- Memory usage
        |
        +-- Logs & Data
        |   |-- Logging toggle (enable/disable session file writing)
        |   |-- Sessions / Events / Measurements counters
        |   |-- Purge Logs button
        |   \-- Factory Reset button
        |
        \-- Lifetime Stats
            |-- Refresh Stats button
            |-- Total grinds, shots, weight
            |-- Motor runtime, uptime, accuracy
            \-- Pulse counts

During Grinding:
|-- Weight display & progress
|-- Tap anywhere: Arc ↔ Nerdy display modes
|-- STOP button
\-- Purge Confirmation (appears in Purge mode after grinder saturation)
    |-- "Grinder Purged" title
    |-- Instruction message
    |-- "Keep purge grinds from now on" checkbox
    \-- CONTINUE button
```

---

## ⚡ Automated Grind Flow

Want the scale to run itself? Enable the automation toggles in **Menu → Grind Settings**:

- **Start on Cup**: As soon as a recognized cup or portafilter lands on the load cell (≈50 g delta inside a 2 s window), the active profile tars and begins grinding automatically. Ideal when dosing cups dock directly under the chute.
- **Return on Removal**: When the cup weight drops away after completion, the grinder exits the results screen and returns to Ready. Useful for keeping the workflow hands-free between shots.

Both automation settings rely on the same smoothed weight deltas used for flow detection, so no extra calibration is required. Leave them disabled if you prefer manual control or experience false triggers with lighter accessories.

---

## 🔵 Bluetooth Connectivity

Bluetooth is on by default and stays on — there is no inactivity timer, so a client can connect at any time without a trip to the menu. It can be configured in **Menu → Bluetooth**: the *Enabled* toggle turns the radio off until the next reboot, and the *Startup* toggle (on by default) controls whether it comes back up at boot. Turn both off for a permanently offline grinder. The blue Bluetooth symbol in the top-right corner indicates when active. Bluetooth enables wireless firmware updates via BLE OTA, grind data export and analytics, and device management. Grind session logging is on by default and can be toggled under **Menu → Logs & Data**; cancelled grinds are never saved, and the oldest sessions are purged automatically when flash space runs low.

---

## 🔍 Diagnostic Report

Generate a comprehensive diagnostic report from your device for troubleshooting or attaching to GitHub issues. The report includes firmware version, system health metrics, load cell diagnostics, and all compile-time parameters.

### Report Contents

- **Firmware Information**: Version, build number, git commit, branch, and build timestamp
- **System Runtime**: Uptime, CPU frequency, heap memory usage, flash size, and driver type
- **Runtime Diagnostics**:
  - Load cell calibration status and factor
  - Noise levels (standard deviation in grams and ADC units)
  - Noise acceptability assessment
  - Motor response latency (default or auto-tuned value)
- **Compile-Time Parameters**: Profile defaults, weight/time ranges, screen settings, auto-grind thresholds, and all user-configurable constants

### Access Methods

**Web Flasher (Recommended):**
1. Visit the [Web Flasher Tool](https://coffeegrinder.preetpatel.com)
2. Navigate to the **Diagnostics** tab
3. Click "Connect & Get Diagnostics"
4. Copy to clipboard or download the report as a text file

**Command Line:**
```bash
# Display report in terminal
python3 tools/grinder.py diagnostics

# Save report to file
python3 tools/grinder.py diagnostics --save diagnostic-report.txt
```

**When to Use:**
- Reporting bugs or issues on GitHub (attach the report to your issue)
- Verifying calibration status and noise levels
- Checking motor latency settings after auto-tune
- Confirming firmware version and compile-time parameters
- General troubleshooting and system health assessment

---

## 📊 Analytics & Data Export

Grind session logging is **on by default** (toggle under **Menu → Logs & Data**), so every completed grind is ready to analyze — cancelled grinds are never saved, and the oldest sessions are purged automatically when flash space runs low (roughly 100+ sessions fit).

### Analyze in the Browser (No Local Tools)

The [Web Flasher Tool](https://coffeegrinder.preetpatel.com)'s **Analytics** tab pulls grind sessions, system info, and the diagnostics report straight from the grinder over Web Bluetooth (Chrome/Edge) and renders the full analysis dashboard in the browser — single-session phase charts, vibration/FFT analysis, session-overlay comparison, multi-session statistics, long-term trends with a burr-wear odometer, and the Device Health view. Data is cached in the browser between visits and can be exported/imported as JSON for sharing.

[Analytics — single-session analysis](../media/analytics.png) [Analytics — device health snapshot](../media/analytics-health.png)
[Analytics — aligned session comparison](../media/analytics-compare.png) [Analytics — long-term trends and burr-wear odometer](../media/analytics-trends.png)

### Launch Interactive Dashboard
```bash
# Pull grind data + system info + diagnostics over one BLE connection,
# then launch the Streamlit dashboard (Device Health view shows the snapshot)
python3 tools/grinder.py analyze

# Or view reports from existing data
python3 tools/grinder.py report
```

### Available Tools
```bash
python3 tools/grinder.py --help          # Show all available commands
python3 tools/grinder.py scan            # Scan for BLE devices
python3 tools/grinder.py connect         # Connect to grinder device  
python3 tools/grinder.py debug           # Stream live debug logs
python3 tools/grinder.py info            # Get device system information
python3 tools/grinder.py export          # Export grind data to database
```

### Tools Directory Structure
- **`grinder.py`**: Cross-platform Python tool for all operations (build, upload, analyze)
- **`ble/`**: BLE communication tools and OTA update system
- **`streamlit-reports/`**: Interactive data visualization and analytics
- **`database/`**: SQLite database management for grind session storage

---

## 🧠 Algorithm Details

### Grinding Algorithm

The system uses a **zero-shot learning algorithm** requiring no prior knowledge or manually tuned variables. It instantly adapts to changes in temperature, humidity, grinding coarseness, bean type, and hardware characteristics.

**Multi-Phase Approach:**

1. **Initialization & Taring Phase**
   - Automatic tare on grind button press
   - 30-second timeout from grind start to completion
   - Noise-adaptive settling detection

2. **Grinder Saturation Phase** (Weight mode only)
   - Saturates the grinder before main grind for accurate latency detection
   - Configurable amount: 0.1g-5.0g (default 1.0g)
   - **Prime mode**: Keeps coffee, continues immediately after settling
   - **Purge mode**: Shows confirmation popup, waits for user to discard stale grinds
   - Logging and chart updates disabled during purge confirmation

3. **Predictive Phase**
   - Learns flow rate and motor-to-cup latency (relay + motor inertia + burr spin-up)
   - Predicts when to stop motor based on measured flow and coast characteristics
   - Target: barely undershoot target weight (overshoot is unrecoverable)
   - Uses runtime-configurable motor response latency (30-200ms, default 50ms)

4. **Pulse Correction Phase**
   - Conservative pulse duration calculation using 95th percentile flow rate
   - Closed-loop flow feedback: each pulse's settled yield re-derives the flow
     estimate for the next pulse (sanity-clamped), so a mis-estimated rate is
     corrected after one pulse instead of persisting all session
   - Cross-session pulse gain: the ratio of measured to predicted pulse flow is
     learned as a slow EWMA (~5-grind memory, clamped to 0.5-2.0, persisted in
     NVS) and seeds the first pulse of every grind - the ratio is dimensionless,
     so it survives bean and grind-setting changes that shift absolute flow
   - Bounded pulses respect hardware-specific motor response latency
   - Pulses range from motor latency minimum to latency + 225ms maximum
   - Mechanical instability detection (3+ sudden weight drops triggers diagnostic)
   - Repeats until target ± tolerance reached

5. **Additional Top-Up Pulses (weight and time mode)**
   - Dedicated `TIME_ADDITIONAL_PULSE` phase for post-completion grinding
   - 100ms fixed pulse duration, delivered by hardware RMT so the timing is exact
   - Split-button UI: OK + PULSE buttons on completion screen
   - The phase is held until the scale settles, so the displayed weight and the final weight
     include the full pulse yield and a second tap cannot land before the first is measured
   - Not captured in the stored session log: the session is finalized when the grind first
     reaches `COMPLETED`, so the logged final weight excludes any top-up pulses

**Motor Response Latency Model:**

The motor response latency represents the physical system lag between relay activation and grounds production. This value is hardware-specific and accounts for:
- Relay closure time (solid-state vs mechanical relays)
- Motor inertia (110V vs 220V motors)
- Burr spin-up characteristics (different grinder models/designs)

The latency value is automatically calibrated via **Auto-Tune Motor Response** (Menu → Tune Pulses) using binary search with statistical verification, or uses a safe 50ms default. This enables universal grinder compatibility without firmware modifications.

**Key Features:**
- Noise-resistant through multi-modal load cell measurement (instant, smoothed, filtered)
- Hardware-adaptive pulse control via runtime motor latency
- Conservative approach: undershoots target, then corrects with bounded pulses
- Mechanical instability detection with hysteresis and persistence
- 30-second grind timeout protection with user acknowledgment requirement

---

## ❓ Frequently Asked Questions

**Will this modification work on grinders other than the Eureka Mignon Specialita?**

See the comprehensive **[Grinder Compatibility Matrix](GRINDER_COMPATIBILITY.md)** for detailed compatibility information across different grinder models, including confirmed compatible models, adaptation requirements, and installation methods.

**Can I use this to grind directly into a portafilter instead of a dosing cup?**

Yes, but requires modifications: use 1kg load cell (vs 0.3kg) for better accuracy with heavier portafilters. Design and 3D print custom portafilter holder mounting to load cell. The dosing cup holder design serves as reference for portafilter adapter.

---

## 🔧 Troubleshooting

For common build and setup issues, see **[TROUBLESHOOTING.md](TROUBLESHOOTING.md)**.

---

For additional support, refer to the project repository issues section, but please note that support availability is limited as mentioned in the project status.

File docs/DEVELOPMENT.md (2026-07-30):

# Development Guide

This guide is for developers who want to build the Smart Grind-by-Weight firmware from source, contribute to the project, or modify the code for their own use.

**End users:** If you just want to use the device, download pre-built firmware from [Releases](https://github.com/preetpatel/smart-grind-by-weight/releases) instead.

---

## 🛠️ Development Setup

### Prerequisites

- **Python 3.8+** with pip
- **Git** for version control
- **USB cable** for initial firmware flashing
- **Hardware** (ESP32-S3 board, HX711, load cell) for testing

### Initial Setup

1. **Clone the repository:**
   ```bash
   git clone https://github.com/preetpatel/smart-grind-by-weight.git
   cd smart-grind-by-weight
   ```

2. **Install development dependencies:**
   ```bash
   python3 tools/grinder.py install
   ```

This automatically creates a virtual environment and installs all required dependencies including PlatformIO.

---

## 🔧 Build Targets

The project has three build targets:

### Production Target: `waveshare-esp32s3-touch-amoled-164`
- **Use case:** Real hardware with load cell and grinder connected
- **Hardware:** Full ESP32-S3 + HX711 + load cell + grinder motor relay
- **Features:** All functionality enabled
- **Optimizations:** `-Ofast` optimization level for performance

### Debug Target: `waveshare-esp32s3-touch-amoled-164-debug`
- **Use case:** Development and debugging with real hardware
- **Hardware:** Full ESP32-S3 + HX711 + load cell + grinder motor relay
- **Features:**
  - All functionality enabled
  - Debug symbols included
  - 2-second UI serial delay for easier debugging
  - Serial monitor filters to suppress harmless touch driver errors

### Mock/Development Target: `waveshare-esp32s3-touch-amoled-164-mock`
- **Use cases:**
  - Development without connected load cell or grinder
  - Testing with device installed in grinder without wasting beans or taxing the motor
- **Hardware:** Can run on just the ESP32-S3 Waveshare board (without HX711 or grinder) OR with full hardware installed
- **Features:**
  - Simulated load cell readings (green background indicates mock HX711 driver is active)
  - Mock grinder motor (visual indicator instead of relay activation)
  - Debug features enabled

**Mock mode benefits:**
- Develop UI changes without affecting the actual grinder
- Bring your waveshare board with you for coding and testing on the road :)
- Work on new features without hardware setup or bean waste
- Capture USB serial messages for debugging

---

## 🚀 Building & Flashing

### Development Platform

This project uses the **pioarduino ESP32 platform** (a community fork) instead of the standard Espressif ESP32 platform. This ensures proper support for the Waveshare ESP32-S3 AMOLED display.

**Platform Details:**
- **Platform**: [pioarduino/platform-espressif32](https://github.com/pioarduino/platform-espressif32) (stable release)
- **Framework**: Arduino ESP32 Core 3.x
- **Target**: ESP32-S3 with AMOLED touch display

The platform dependency is automatically handled by PlatformIO via the `platformio.ini` configuration.

### Build Commands

**Build production firmware:**
```bash
python3 tools/grinder.py build
```

**Build debug firmware:**
```bash
python3 tools/venv/bin/python -m platformio run -e waveshare-esp32s3-touch-amoled-164-debug
```

**Build mock/development firmware:**
```bash
python3 tools/venv/bin/python -m platformio run -e waveshare-esp32s3-touch-amoled-164-mock
```

**Clean build artifacts:**
```bash
python3 tools/grinder.py clean
```

### Host Tests

```bash
python3 tools/grinder.py test
```

Compiles and runs every `tools/tests/*.cpp` against `src/` with the host compiler — no
PlatformIO toolchain and no device required. These cover pure logic that is impractical to
verify on hardware: RMT pulse-timing arithmetic, flow-rate percentile selection under a
negative calibration factor, and `millis()` rollover windows. The same command runs in CI on
every push and pull request (`.github/workflows/tests.yml`), so add a test here whenever you
change that kind of logic.

### Initial USB Flashing

For the first-time setup or when BLE isn't working:

```bash
# Build and upload via USB (production)
python3 tools/grinder.py build
python3 tools/venv/bin/python -m platformio run --target upload -e waveshare-esp32s3-touch-amoled-164

# Or for debug target
python3 tools/venv/bin/python -m platformio run --target upload -e waveshare-esp32s3-touch-amoled-164-debug

# Or for mock target
python3 tools/venv/bin/python -m platformio run --target upload -e waveshare-esp32s3-touch-amoled-164-mock
```

### BLE OTA Updates (After Initial Setup)

Once the device is running and connected to Bluetooth:

```bash
# Build and upload wirelessly (production)
python3 tools/grinder.py build-upload

# Upload specific firmware file
python3 tools/grinder.py upload path/to/smart-grind-by-weight-vX.X.X.bin

# Force full firmware update (skip delta patching)
python3 tools/grinder.py build-upload --force-full

# Scan for BLE devices
python3 tools/grinder.py scan

# Get device system info
python3 tools/grinder.py info
```

Upload commands keep scanning and retrying the BLE connection until the grinder is available. Press `Ctrl+C` to stop waiting.

---

## 📦 Release Process

For maintainers creating releases, see **[RELEASES.md](RELEASES.md)** for detailed release workflow documentation.

---

## 🐛 Debugging

### Serial Monitor

```bash
# Monitor serial output via PlatformIO
python3 tools/venv/bin/python -m platformio device monitor
```

### BLE Debug Monitoring

```bash
# Live debug monitoring via BLE
python3 tools/grinder.py debug
```

**⚠️ BLE Monitoring Limitations:**
- **Boot messages are missed** - BLE connection establishes after device boot
- **Kernel panics not captured** - System-level crashes bypass BLE and go directly to serial
- **Framework messages missing** - Low-level Arduino/ESP-IDF messages don't route through BLE
- **Best for application debug** - Primarily receives debug messages from the smart-grind-by-weight firmware itself

For complete debugging (including boot sequence and system messages), use USB serial monitoring.

---

## 📚 Additional Documentation

- **[DOC.md](DOC.md)** - Complete build instructions and parts list
- **[TROUBLESHOOTING.md](TROUBLESHOOTING.md)** - Common issues and solutions
- **[GRINDER_COMPATIBILITY.md](GRINDER_COMPATIBILITY.md)** - Adapting to different grinder models
- **[RELEASES.md](RELEASES.md)** - Release process and versioning

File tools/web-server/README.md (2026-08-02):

# Grinder Web App

One Next.js app — strict TypeScript, Biome, pnpm — serving everything web for
the grinder (design: `docs/CLOUD_SYNC.md`):

1. **The device UI** — an adaptive home (`/`) that shows the pairing path to
   new visitors and the grinder's own status to owners, plus
   `/grinder/{get-started,update,wifi,diagnostics}`: USB install via
   esp-web-tools, BLE OTA, WiFi + cloud provisioning, and the diagnostic
   report. The grinder itself is the sidebar's workspace switcher.
2. **The analytics dashboard** (`/analytics`) — full grind analysis from a
   BLE pull or the cloud store, rendered with Plotly: an overview, a
   filterable session table (`/analytics/sessions`), per-grind deep dives at
   `/analytics/session/[sha]` (addressable by content hash, so a link to one
   grind survives re-pulls and factory resets), plus compare, multi-session,
   trends and device health.
3. **Accounts** (`/signin`, `/account`) — Better Auth (email/password,
   passkeys, GitHub when configured). Cloud stores belong to accounts, so
   dashboards follow the user to any signed-in browser; read-only `#store=`
   share links need no account.
4. **The cloud sync API** — `/api/stores/...`: owner-session store management,
   the device manifest handshake, raw session-blob ingest with content-hash
   dedup, health snapshots, and key-authed read endpoints for share links and
   the Python tooling.
5. **The firmware release proxy** — `/api/firmware[/tag/asset]` lists GitHub
   releases and streams their assets same-origin, replacing the old GitHub
   Pages deployment and its CI asset copying entirely.

## Development

```bash
pnpm install
cp .env.example .env.local     # then fill in (BETTER_AUTH_SECRET=$(openssl rand -hex 32))
pnpm dev                       # Next on :3000
pnpm test                      # vitest against in-process PGlite Postgres
pnpm typecheck                 # strict TypeScript
pnpm lint                      # Biome (lint + format check); lint:fix / format to write
```

`lib/parser.ts` is the single JS/TS parser for the firmware's session files,
shared by the browser dashboard and the server's ingest validation; the
Python parser (`tools/ble/grinder-ble.py`) is the only other consumer — keep
both aligned with `src/logging/grind_logging.h` (see `tools/ble/CLAUDE.md`).

Drizzle migrations live in `drizzle/` and are generated from `lib/schema.ts`
with `pnpm db:generate`. They are applied automatically on first database use
per process (serverless-friendly), both in production and in tests. The
Better Auth tables (`lib/auth-schema.ts`) were transcribed from
`@better-auth/cli generate` — regenerate and diff when upgrading better-auth.

## Auth model (summary — full design in `docs/CLOUD_SYNC.md`)

- Creating and managing cloud stores requires a signed-in account; every
  store has an `owner_id` from birth.
- The device authenticates uploads with its `upload_key` (stored hashed;
  rotated on every provision — the server never holds a usable write
  credential at rest).
- `view_key` powers read-only dashboard share links and the BLE
  claim-by-possession flow; it is deliberately semi-public.
- Email/password has **no password reset** (no mail service). The UI pushes
  linking GitHub or adding a passkey as the recovery path.

## Deploying

**Hosted (Vercel):** set the project root to `tools/web-server` and provide
the environment below (Neon / Vercel Postgres for `DATABASE_URL`). Session
blobs are stored as Postgres `bytea` — no separate blob store.

**Self-hosted (Docker):**

```bash
cd tools/web-server
BETTER_AUTH_SECRET=$(openssl rand -hex 32) docker compose up -d
```

Point the app's WiFi & Backup provisioning at `http://<host>:3000`. The
compose file disables the per-store session quota (`SYNC_SESSION_QUOTA=0`).
Put a reverse proxy (Caddy, Tailscale, nginx) in front for TLS if the server
is reachable beyond your LAN — passkeys and Web Bluetooth both need a secure
context anyway.

## Environment

| Variable | Required | Meaning |
| --- | --- | --- |
| `DATABASE_URL` | yes | Postgres connection string |
| `BETTER_AUTH_SECRET` | yes (prod) | ≥32-char random secret for session cookies (`openssl rand -hex 32`) |
| `BETTER_AUTH_URL` | for GitHub/passkeys | Canonical origin, e.g. `https://coffeegrinder.preetpatel.com` |
| `GITHUB_CLIENT_ID` / `GITHUB_CLIENT_SECRET` | no | Enables the "Continue with GitHub" button. OAuth callback: `{BETTER_AUTH_URL}/api/auth/callback/github` |

## Limits (env-overridable, see `lib/config.ts`)

| Variable | Default | Meaning |
| --- | --- | --- |
| `SYNC_MAX_SESSION_BYTES` | 65536 | Reject larger session uploads |
| `SYNC_MAX_SNAPSHOT_BYTES` | 4096 | Reject larger health snapshots |
| `SYNC_SESSION_QUOTA` | 10000 | Per-store cap; oldest rotate out (0 = off) |
| `SYNC_UPLOADS_PER_HOUR` | 200 | Per-store ingest rate limit |
| `SYNC_STORES_PER_USER` | 20 | Stores per account (a store ≈ one grinder) |

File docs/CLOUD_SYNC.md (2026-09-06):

# Cloud Sync — Design

Grind sessions sync from the grinder to an ingest server over WiFi. The ESP32 keeps its
existing space-bounded flash buffer (~100+ sessions); the server holds the full,
unbounded history and serves the analytics dashboard over it. This document records the
agreed design; each decision was made deliberately — change them knowingly.

## Product shape

- **One web app, two deploy targets.** A single Next.js app (`tools/web-server`) serves
  the existing web flasher (static assets, unchanged), the analytics dashboard, and the
  ingest/read API. It deploys to Vercel (the hosted service, replacing GitHub Pages) and
  ships as a Docker image (`docker compose up`: app + Postgres) for self-hosters. No
  Vercel-only APIs in core logic; the storage contract is a Postgres connection string.
- **The server is both dashboard and archive.** The dashboard renders full history
  (long-term trends, burr odometer, device health) — the views that suffer most from the
  ESP's session cap. A raw export endpoint keeps the Python tooling alive.
- **Firmware needs nothing except provisioning.** A device is configured over BLE with
  `{base_url, store_id, upload_key}`; everything else is server-side. Sync is **off until
  explicitly provisioned** — no phone-home of any kind without opt-in.

## Data model

- **Wire format = flash format.** The ESP uploads session files verbatim (packed structs:
  `TimeSeriesSessionHeader` + `GrindSession` + events + measurements, ~15–36 KB). No
  on-device JSON. The server is the third consumer of `grind_logging.h` (alongside the
  Python parser and `analytics/parser.js`) — struct changes must update it too.
- **Blob is truth, summary is index.** The server stores the raw blob verbatim (Postgres
  `bytea` — ~30 KB blobs are far below any bytea concern, and ingest is transactional:
  summary row + blob commit atomically). At ingest it parses only the header + the 80-byte
  `GrindSession` summary into an indexed `sessions` row (timestamp, target/final weight,
  error, mode, pulse count, termination reason, duration). Measurements stay in the blob
  and are parsed in the browser on demand by the existing `parser.js`. Schema evolution =
  version-aware parser over immutable blobs, never a time-series migration. The summary
  table is disposable: re-derivable from blobs.
- **Identity & dedup: `(store_id, sha256(blob))`.** The server computes SHA-256 at
  ingest; an identical blob re-uploaded to the same store is silently dropped. Same
  `session_id`, different hash → stored (NVS counter reset after factory reset, not a
  duplicate). Uniqueness is scoped to the store rather than the device so browser
  backfills from firmware that predates the device-id characteristic stay consistent
  with later device uploads — byte-identical 20 KB blobs from *different* grinders
  don't occur in practice. `device_id` (the ESP's factory MAC, `ESP.getEfuseMac()`,
  also exposed in the BLE system-info JSON) is stored as metadata on every row, and is
  the key the store itself is bound to — see "One grinder, one store". The
  header checksum — a real zlib CRC-32 since this feature landed; 0 in legacy files —
  is verified at ingest when nonzero, for corruption rejection only, not identity.
- **Health snapshots ride along.** After each successful sync the device POSTs the same
  compact snapshot it serves over BLE (lifetime stats, diagnostics state, firmware
  version, OTA outcome; < 1 KB). Keyed `(device_id, received_at)`, kept as timestamped
  observations — this turns the Health view into a *history* (noise creep, calibration
  drift, error-rate vs firmware version), which BLE-only "now" reads can never show. Also
  feeds the burr odometer (lifetime stats predate the server and survive purges) and an
  update-available nudge.

## Sync protocol

- **Manifest handshake; the server is the only sync state.** Each window the device sends
  a manifest built from the 24-byte headers already on flash — one
  `(session_id, session_timestamp, session_size, checksum)` tuple per file (~a few bytes
  each). The server replies "send me these N"; the device POSTs just those, sequentially,
  one plain HTTP POST per session. Zero sync state in NVS. Wipe the server → next window
  re-uploads everything automatically; nothing to reset on the device. Tuple matching
  (not bare id) covers the counter-reset case.
- **No resume/chunking cleverness, ever.** Sessions are ≤ 36 KB; a failed POST is healed
  by the next manifest handshake by design.
- **Trigger = a rule, not an event:** inside a cloud window, run a manifest sync if a new
  session or brew record exists. The uploader is the second `WifiService` consumer (the
  seam the service was built for), and it owns the only recurring window there is: one
  opens `CLOUD_SYNC_GRIND_DELAY_MS` (30 min) after the last grind or brew record, with
  WifiService's existing gating (never during grind/OTA/BLE export) and backoff. No new
  retry machinery.
- **The radio comes up at exactly two moments, and the uploader owns one of them.** The
  boot window is `CLOCK_ONLY` — SNTP, then the radio goes off — so the TLS handshake never
  lands on the startup current draw. There is no daily window: a stale clock is refreshed
  inside a cloud window that is already open. The scheduling decisions are pure functions
  in `src/system/sync_schedule_logic.h`, host-tested in `tools/tests/test_sync_schedule.cpp`.
  This is a power-supply accommodation — see the brownout note in CLAUDE.md before
  reintroducing any periodic sync.
- **Transmit power is budgeted as well as scheduled.** Every Wi-Fi window applies
  and reads back an 8.5 dBm ceiling (`WIFI_MAX_TX_POWER_QDBM = 34`) before
  association and verifies minimum modem sleep. A configuration failure closes
  the window and uses the existing backoff; it never falls back to full power.
  BLE Wi-Fi status exposes `last_tx_power_qdbm` for verification. This targets
  the brownouts seen during idle cloud sync in September even after the
  30-minute scheduling delay. It may reduce range and requires validation on
  the stock supply; it does not cap total board or PHY startup current.
- **A backlog is swept by the next grind, not at boot.** Sessions written before a reset
  do not open a window on their own, but the manifest offers every file on flash, so the
  next window uploads them alongside the new session. Every run restarts the 30-minute
  wait however it ended, so a failing server is retried on that cadence rather than on
  every loop pass.
- **Retries only ever owe the clock.** A window torn down for a grind/OTA/export restarts
  the 30-minute wait at that moment (`defer_window()` — a cancelled grind flushes nothing,
  and would otherwise leave a backlog free to reopen the window seconds after the motor
  stops), and `sync_retry_after` schedules aborted/failed attempts as `CLOCK_ONLY`
  retries: the uploader only ever re-enters through its own quiet delay, never on a retry
  deadline the grinder's activity had no say in. While a retry backoff is pending, waiting
  cloud work holds off and upgrades the retry when it fires; only a provisioning request
  from the panel jumps the backoff.
- **Failure is silent and normal.** Self-hosted servers go down; no UI errors, nothing
  blocks. Status surfaces passively: Menu → Settings → Cloud Sync (last result/time,
  pending count) and the backup row on the web app's home page.
- **Transport: HTTPS to a real domain.** `esp_http_client` + ESP-IDF CA bundle validates
  Let's Encrypt/Vercel certs out of the box — no pinning, no cert provisioning. TLS RAM
  (~40 KB) is paid only inside windows, which never overlap grinds.

## Annotations and deletion

- **Annotations are local-first.** Bean, roast date, grind setting, note and tags are
  keyed by the session's `sha256`, not a foreign key — an annotation written before the
  session finishes uploading still lands on it, and survives re-ingest. The browser
  writes to IndexedDB immediately and works with no account; the `annotations` table is
  the copy that follows an account across browsers. Reconciliation is per row,
  last-write-wins on `updated_at`, so two browsers editing different grinds never
  collide and a stale tab flushing late is dropped rather than applied.
- **Deletion needs a tombstone.** The manifest handshake is stateless by design — it
  asks the server what it lacks — so deleting a row alone invites the grinder to upload
  it again on the next window. `DELETE /api/stores/[id]/sessions/[sha]` (owner session
  only) records `deleted_sessions` with both the content hash and the
  `(session_id, session_timestamp)` pair the device identifies files by, since the
  device cannot know the hash of a file it has not sent. The manifest treats a tombstone
  as "already have it", and ingest rejects a tombstoned blob outright rather than
  trusting the manifest to have been consulted.

## Beans and brew records

- **A bean is one bag** (`beans`: name, brew ratio, shot time, roast date, notes,
  archived_at), owned by the store; `stores.active_bean_id` is the bag in the hopper.
  The server is the source of truth: the dashboard's beans page writes it first, then
  best-effort pushes `{name, ratio, brew_time_s, dose_g, yield_min_g, yield_max_g,
  time_min_s, time_max_s}` to the grinder over BLE
  (`BLE_SYSINFO_BEAN_CONFIG_CHAR_UUID`), and the sync window's config fetch
  (`GET /config`) converges a grinder no browser is near. Both channels carry the same
  server state into the `bean` NVS namespace, so they cannot disagree.
- **A bag states a recipe, not a number** — "dose 20.5 g, yield 27–30 g, time 25–31 s".
  Those numbers routinely contradict the bag's own printed ratio (20.5 × 1.5 = 30.75,
  outside 27–30), so the five recipe columns store what was typed and the ratio becomes
  a derived display value; a range held as a *ratio* range would silently rewrite the
  roaster. All five are nullable — a bean with none behaves exactly as before ranges
  existed. `resolveRecipe` (`lib/beans.ts`, mirrored in `lib/analytics/brew.ts` and by
  `BeanConfig::recipe_for_dose` on the device) resolves them for the dose a grind
  actually delivered: the **yield band scales** by `dose ÷ dose_g`, because the range
  is quoted at a reference dose; the **time band does not**, being an absolute the
  roaster stated. With no stated yield range the band falls back to dose × ratio ±3%
  (`USER_BREW_ON_TARGET_BAND_PCT`); with no stated time range there is deliberately no
  fallback at all, since a tolerance nobody wrote down must not become evidence.
- **Attribution is stamped at ingest**: a session arriving while a bean is active gets
  `annotations.bean_id` filled — only when blank (`coalesce`), and without touching
  `updated_at`, so a hand-picked bean and the LWW reconcile are never overridden.
- **Brew records ride the same identity pair as the manifest.** The grinder's
  post-grind entry screen queues `{session_id, session_timestamp, output_g,
  brew_time_s}` under `/brews` on LittleFS (deliberately not `/sessions`, whose
  retention purge and manifest scan treat every file as a session). `POST /brews`
  resolves the pair to the session's `sha256` and lands `brew_output_g`/`brew_time_s`
  on its annotation row; `stored`/`deleted` (tombstoned) drop the queued file,
  `unknown` keeps it for the next window. The response echoes `{bean, advice}` so a
  logged shot refreshes the verdict in one round trip.
- **Unmeasured time is null, never a default.** `brew_time_s` of `0` (the user skipped
  the time step) or absent (firmware that never asked) both store null. Before this,
  every record carried the bean's pinned 30 s, which made a real 30 s shot
  indistinguishable from an unanswered prompt in the column the advice engine reads as
  evidence. Rows written under the old behaviour cannot be told apart retroactively;
  they are only ever read by the yield-deviation path below.
- **Advice is computed server-side** (`lib/advice.ts`, mirrored client-side in
  `lib/analytics/brew.ts` — change one, change both), and reports which of two readings
  produced it as `basis`. Where the bag states a target time *and* the window's shots
  were really timed (`basis: 'time'`), the clock decides, which is the classic dial-in
  loop: hold the dose and the yield, and let time say whether the grind is too fine or
  too coarse. Each shot's time is first normalised to the middle of its yield band
  (`time × target_yield ÷ output`), so a shot stopped short doesn't read as fast for the
  wrong reason; the median then lands under `time_min_s` → finer, over `time_max_s` →
  coarser. Untimed shots never enter that median — they answered a different question.
  Otherwise (`basis: 'yield'`) the original reading stands: with time assumed fixed,
  output deviation is a flow proxy, median of the last 5 shots beyond ±8% meaning finer
  (ran fast) or coarser (choked). Both need at least 3 shots, and a recorded
  grind-setting change resets the evidence either way. The grinder does not render
  the verdict - its ready-screen chip shows the last shot's own numbers instead
  (see below) - so thresholds evolve without firmware releases and the advice stays
  a dashboard surface.
- **Bag tracking follows the same split.** An optional `beans.bag_size_g` enables it:
  the server sums the doses of every session attributed to the bag, estimates the
  per-shot dose from the median of the last 10, and ships
  `bag: {size_g, used_g, shots_remaining, low}` (low at ≤5 shots) alongside the
  advice in `GET /config` and the `POST /brews` echo. The grinder holds it as
  runtime-only state and shows "N SHOTS LEFT" on the shared ready-screen chip — bag
  warnings outrank the last-shot readout, and a dismissed warning returns when the
  count drops. Purge-mode waste isn't in the session summary, so the estimate runs
  slightly optimistic; the threshold absorbs it.

The ready-screen chip itself (`src/system/last_shot.*`) is local, not synced: each
completed grind writes `{session_id, dose_g}` to one NVS blob (top-up pulses rewrite
it, since they re-enter COMPLETED with the updated weight), and a saved shot log
stamps its weight out (`yield_dg`, decigrams so the blob keeps its pre-yield size and
old records still load) and `brew_time_s` onto the matching record - guarded by
session id, so a prompt superseded by a newer grind can't mislabel its shot. The chip
reads "LAST 36.0G • 28S" - the shot's weight out and time; time drops off when that
step was skipped, and until the shot is logged the dose stands in. The separator is
U+2022 BULLET because the built-in montserrat fonts don't carry U+00B7 MIDDLE DOT
(it drew a missing-glyph box). Tap dismisses until the next dose or shot arrives; it
survives reboot by design.

## Auth model — device is the credential

- **Accounts own stores; the device stays a bearer-key client.** Browser-side cloud
  flows require a signed-in account (Better Auth: email/password always, passkeys on
  top, GitHub when the deployment configures an OAuth app — `lib/auth-server.ts`,
  tables in `lib/auth-schema.ts`). Every store carries a non-null `owner_id` from
  birth; the owner's session cookie is the write credential for browser requests
  (`authStore` tries session first, then bearer keys) and the *only* credential for
  store management (create/rename/delete/provision/rotate — `authOwner`). The
  firmware knows nothing about accounts: it uploads with its `upload_key` exactly as
  before. No mail service exists, so there is **no password reset** — the sign-in UI
  says so and pushes GitHub-linking or a passkey as the backup way in. On `/account` that
  warning is **conditional on actually having no way back in** (no linked GitHub *and* no
  passkey); as a permanent subtitle it kept warning about lost access to accounts that
  already had both.
- **Credential UX is password-manager-first.** The auth forms carry the markup managers
  (1Password, Keychain, Chrome) match on: `name` attributes, `autocomplete="username"` on
  the email field, `new-password`/`current-password` on the right side of the sign-in ↔
  sign-up toggle, and a `key={mode}` remount so the form re-reads as a *registration*
  form and offers to save. Change-password on `/account` includes the read-only username
  field managers need to know which login to update. The sign-in email field also carries
  the `webauthn` token and arms passkey conditional UI, so saved passkeys appear in the
  same autofill dropdown. The grinder's WiFi/PSK fields are marked `data-1p-ignore` —
  they are the appliance's credentials, not a login for this site.
- **Two keys per store, one job each.** `upload_key` is the device's HTTP credential:
  stored **hashed**, and **rotated on every provision** — any signed-in browser can
  provision a device (`POST /api/stores/[id]/provision` mints a fresh key for the BLE
  write), yet a DB dump never leaks a usable write credential. `view_key` is the
  semi-public read credential behind `#store=` share links and BLE claims: stored
  plaintext so any owner browser can produce a share link. Upload ⊇ view for reads;
  read ≠ write: sharing a dashboard never hands out write access.
- **Claim by possession is read-only.** Any browser reading a provisioned grinder over
  BLE gets `store_id + view_key` and becomes a *viewer* (exactly a share link). Owners
  get full access by signing in — which is also what syncs dashboards across browsers.
- **One grinder, one store.** `stores.device_id` holds the grinder's factory MAC under a
  partial unique index (NULL = unbound), so the 1:1 rule is a database constraint rather
  than UI etiquette in one component. `POST /api/stores` is idempotent per device and
  requires one: the caller's own grinder gets its existing store back with a freshly
  rotated upload key (creating *is* provisioning), an unknown grinder gets a new store,
  and the per-account cap (`SYNC_STORES_PER_USER`) is only a backstop. That is what makes
  a second browser, a Forget Sync or a factory reset land back on the same history instead
  of orphaning it in a store nothing points at any more. `POST /api/stores/[id]/provision`
  optionally carries a `device_id`, binding a store that has none (migrated, or released)
  and refusing one that already belongs to a different grinder. Ingest checks
  `x-device-id` against the binding on key-authed requests (403 `device_mismatch`), which
  closes the two-grinders-one-store direction; browser backfill rides the owner's cookie
  and is exempt, since local records carry no per-record device id. Existing stores
  adopted the grinder that had most recently uploaded to them (migration `0002`).
- **Takeover is possession-gated and moves no data.** Claiming a grinder registered to
  another account requires the `store_id + view_key` pair the device itself hands out over
  BLE. It unbinds the previous store — which keeps every grind as a readable archive for
  its owner — and creates an *empty* store for the claimant, so a resold grinder never
  carries its history to the new owner. `POST /api/stores/[id]/release` is the deliberate
  version of the same thing, and the one that works without the grinder in hand. Known
  limit: a `#store=` share link carries that same view key, so a link recipient could
  claim the grinder; the blast radius is "uploads fail until re-provisioned", never data
  disclosure, and closing it properly needs a device-attested nonce (a firmware protocol
  change). Forget Sync deliberately does *not* release — the grinder keeps its home so
  setting sync up again returns to the same history.
- **CSRF/CORS split.** Wildcard CORS survives only on the key-authed routes (device
  ingest + cross-origin share-link reads carry no cookies). Session-authed routes are
  same-origin: Better Auth checks origins on its own endpoints; custom session
  mutations go through `assertSameOrigin` on top of SameSite=Lax cookies.
- **Lifecycle.** Store delete (cascade: blobs, summaries, snapshots, store), grinder
  release and `view_key` rotation are owner-session actions (Account page, WiFi & Backup,
  and Revoke shared links in the analytics cloud bar). After a
  view-key rotation, re-provision the device so future BLE claims hand out the fresh
  key. `upload_key` leak recovery = just provision again (rotation is the mechanism).

## Limits (hosted)

- Upload size: reject > 64 KB sessions / > 4 KB snapshots at the edge, pre-storage.
- Checksum-invalid blobs rejected at ingest.
- Rate limit ~200 uploads/hour per store key (first-sync burst ≈ 100 fits).
- Quota: 10,000 sessions per store (~300 MB worst case, ≈ 5+ years at 5 grinds/day),
  counted on the summary table. Over quota → rotate oldest (mirrors the device's own
  ring-buffer behavior; recent grinds are the valuable ones) + dashboard banner pointing
  at self-hosting. Self-host: configurable/off.

## UX placement

- **Masthead:** account slot (sign in / email → `/account`). `/signin` offers GitHub
  (env-gated), email/password and passkey one-tap; `/account` manages sign-in methods,
  passkeys, the account's stores (each showing its grinder, or an *Archive* badge when
  unbound — rename / share link / release / delete) and account deletion (typed
  confirmation, cascades stores).
- **One grinder, one name.** The sidebar switcher reads `grinderRegistry` in localStorage
  (labelled from the BLE advertised name at pairing: "GrindByWeight", "GrindByWeight 2");
  the store carries its own `name`. These used to drift — renaming the backup left the
  sidebar on the generic label. Renaming in *either* place now sets both:
  `ble.renameByDeviceId()` joins them on the factory MAC (the registry is keyed by the
  browser's Web Bluetooth device id, the store by the MAC, and the snapshot carries the
  MAC), and the switcher's own Rename pushes to the bound store when one is owned. The
  store lookup happens inside the rename handler, not on render — the sidebar is on every
  page and otherwise has no need for the account's stores.
- **Auth has its own frame.** The app shell lives in the `app/(app)` route group; `/signin`
  sits in `app/(auth)`, which renders one centred column and a link home instead of a
  sidebar full of grinder routes a signed-out visitor can't use. URLs are unchanged —
  route groups don't appear in the path.
- **`/account` is a list of facts, each with its action attached.** *Signing in* holds the
  two singleton methods (password, GitHub) as one row each; **passkeys get their own
  section**, because they are a collection you add to and remove from and because a row
  labelled "This Mac" says nothing about what it is without a heading over it — that
  section carries *Add a passkey* on its heading line and an empty state of its own.
  Backups are one row per store, with
  *Copy link* inline and rename / release / delete behind a `⋯` menu — the grinder id lives
  in that menu rather than the row, being a lookup rather than something you scan a list by.
  Every row is one line: name left, state right, action last, stacking under `sm`. Nothing that is used
  once a year sits expanded: change-password and account deletion are dialogs
  (`components/auth/{change-password,delete-account}-dialog.tsx`), so the page stays
  scannable and an irreversible form is never one stray click from submitting.
- **Web app:** the WiFi page is **WiFi & Backup** — one flow provisions both (the coupling is
  real: sync needs WiFi). Requires sign-in. It reads the grinder *live* over BLE first —
  never the cached snapshot, which is how a browser with cold `localStorage` used to mint
  a duplicate store — then lets the server pick the store from the device id and writes
  the credentials back over BLE in the same session. Setting up cloud backup is only
  offered here, with a grinder present; the analytics bar links to it rather than
  creating a storeless backup. Forget Sync offers server-side deletion only to the owner.
- **Analytics: sources resolve owned-first.** Signed-in accounts get their stores (an
  explicit pick in `sgbwActiveStore` localStorage wins, then the store bound to the
  connected grinder, then the newest; a picker appears when they own several);
  otherwise a viewer link (`#store=` fragment or BLE claim, `sgbwCloudViewer`
  localStorage — no secrets beyond the semi-public view key). The cloud store is a
  superset of any BLE pull whenever reachable, so no merging. A BLE pull auto-backfills
  owned stores through the same idempotent ingest endpoint using the session cookie.
- **Device:** Menu → Settings → Cloud Sync (WiFi page pattern): enable toggle, status
  rows, Forget Sync.

## Implementation map

- **Server:** `tools/web-server` — Next.js (app router, strict TypeScript, Biome) +
  Drizzle/Postgres. Schema `lib/schema.ts` + `lib/auth-schema.ts` (migrations in
  `drizzle/`), ingest `lib/ingest.ts` (validates with the shared `lib/parser.ts` —
  the same TS parser the browser dashboard uses), request auth `lib/auth.ts`,
  Better Auth instance `lib/auth-server.ts` (lazy over `getDb()`; mounted at
  `app/api/auth/[...all]`), limits `lib/config.ts`, grinder identity
  `lib/device-id.ts`, routes under `app/api/stores/` (including `[id]/provision`
  and `[id]/release`) and `app/api/me/`. Checks: `pnpm test` (vitest + PGlite, real route handlers —
  including real Better Auth sign-ups), `pnpm typecheck`, `pnpm lint` (Biome).
  Deploy: Vercel (root `tools/web-server`) or `docker compose up` (app + Postgres,
  quota off; needs `BETTER_AUTH_SECRET`).
- **Firmware:** `src/system/cloud_sync.{h,cpp}` (uploader; NVS `cloudsync`),
  `WifiService::State::UPLOADING` (`src/system/wifi_service.*`), CRC-32 in
  `src/logging/grind_logging.cpp`, BLE characteristics in `src/config/bluetooth.h` +
  `src/bluetooth/manager.*`, settings page in `src/ui/screens/menu_screen.*` +
  `src/ui/controllers/menu_controller.*`, limits in `src/config/cloud_sync.h`.
- **Web:** all in `tools/web-server` — `lib/client/cloud.ts` (API client, share
  links, cloud pull/backfill), `components/grinder/wifi-sync-panel.tsx` (WiFi & Backup
  provisioning flow), `lib/analytics/store.ts` (IndexedDB v2 keyed by sha256, raw
  bytes retained), `lib/client/ble.ts` + `components/device-strip.tsx` (cloud status
  in the snapshot + device-strip chip), `app/analytics/page.tsx` +
  `components/analytics/cloud-bar.tsx` (dashboard cloud source).

## Build order

1. **Phase 1 — server first, browser is the first client.** Next.js app + Postgres +
   API + cloud dashboard source + browser backfill (the backfill exercises the exact
   ingest path the ESP will use — the API earns production traffic before any firmware
   ships).
2. **Phase 2 — firmware.** Provisioning characteristic + NVS, WifiService consumer,
   manifest sync + snapshot POST, settings page, WiFi & Backup flasher flow.
3. **Phase 3 — polish.** Python tool pulls from export endpoint, rotation UI niceties,
   device-strip chip refinements.

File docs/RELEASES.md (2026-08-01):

# Release Guide

This project uses automated releases triggered by Git tags. Here's how it works:

### Branch Strategy
- `main` branch: Stable releases only
- `dev` branch or feature branches: Active development
- Pull requests: Reviewed before merging to main

### Creating Releases

When you've tested your code and want to create a release:

```bash
# Use the integrated release tool (recommended)
python3 tools/grinder.py release
```

The release tool will:
1. Show you recent commits since the last release
2. Let you choose version increment type (patch/minor/major/RC/custom)
3. Update firmware version in `src/config/build_info.h` and commit the change
4. Create annotated git tag
5. Push both the commit and tag to trigger automated GitHub Actions

### What Happens Automatically

Once you push a tag (like `v1.0.0`):

1. **GitHub Actions builds the firmware**
   - Compiles for the ESP32-S3 target with the committed version
   - Creates release artifacts (.bin files and packages)
   - Generates OTA patches with heatshrink compression

2. **Updates Web Flasher**
   - Generates the ESP Web Tools manifest alongside bootloader, partition, OTA, and blank NVS images
   - Uploads each artifact to the GitHub Release
   - The hosted web flasher queries GitHub releases directly, so no binary files are committed back to `main`

3. **Creates GitHub Release (as draft)**
   - Generates a changelog under "What's Changed", plus a compare link
     - Final releases diff against the last **stable** tag, so the notes cover the
       whole RC cycle rather than just the last RC
     - Pre-releases diff against the preceding tag, so each RC shows only its own changes
     - `chore: Creating release ...` commits are filtered out
   - Uploads firmware binaries for download
   - Marks as pre-release if tag contains `beta`, `alpha`, or `rc`
   - **You must manually publish the draft release** — review and curate the
     generated changelog before publishing

### Version Numbering

We use semantic versioning (semver):
- `v1.0.0` - Major release (breaking changes)
- `v1.1.0` - Minor release (new features)
- `v1.0.1` - Patch release (bug fixes)
- `v1.0.0-beta.1` - Pre-release (automatically marked as pre-release)

### Pre-releases

Tags containing `beta`, `alpha`, or `rc` are automatically marked as pre-releases:
- `v1.2.0-beta.1` - Beta release
- `v1.2.0-rc.1` - Release candidate
- `v1.2.0-alpha.1` - Alpha release

This keeps experimental versions separate from stable releases.

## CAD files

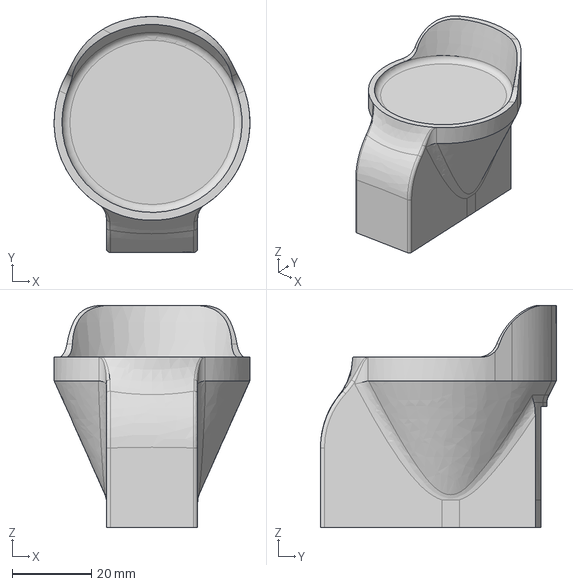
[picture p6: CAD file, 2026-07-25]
3d_files/cup holder - 43mm base forward offset/source/Cup holder (baseline export).step
49.3 x 59.4 x 56.0 mm

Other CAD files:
3d_files/cup holder - 43mm base forward offset/source/Cup holder (baseline export).stl

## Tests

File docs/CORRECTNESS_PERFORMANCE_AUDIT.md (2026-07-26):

# Correctness and Performance Audit

Date: 2026-07-26

Branch: `codex/correctness-performance-audit`

Base: `0ebeeb7` (`fix: misc changes`)

## Scope

Review the motor-control, weight-sampling, calibration, grind-control, and
auto-tune paths for correctness, grind accuracy, and performance. Changes are
limited to defects with a clear impact; broad refactors and speculative tuning
are out of scope.

Hardware and USB debugging are not currently available. Evidence therefore
comes from source inspection, deterministic host checks, and production,
debug, and mock firmware builds. On-device validation remains explicitly
listed below.

## Baseline

Before source changes:

- Production firmware build 29 passed.
- Debug firmware build 30 passed.
- Mock firmware build 31 passed.
- BLE host tests passed: 2 of 2.
- Python tool compilation passed.
- Production RAM: 67,688 bytes; flash: 2,186,035 bytes.
- Debug RAM: 67,688 bytes; flash: 2,273,867 bytes.
- Mock RAM: 67,744 bytes; flash: 2,273,051 bytes.

## Stage 1: Deterministic motor pulses and safe auto-tune

### Findings

1. Long RMT pulses were encoded by looping a compound symbol. The loop repeated
   both the full-duration portion and the remainder, so requested and delivered
   motor-on times diverged substantially. Examples from the original formula:

   | Requested | Encoded HIGH | Error |
   | ---: | ---: | ---: |
   | 100 ms | 68.932 ms | -31.068 ms |
   | 300 ms | 302.912 ms | +2.912 ms |
   | 550 ms | 877.425 ms | +327.425 ms |
   | 1,000 ms | 1,442.953 ms | +442.953 ms |

2. Finite and continuous RMT payloads were local stack arrays. The ESP-IDF RMT
   API requires asynchronous transmit payloads to remain valid until the
   transaction completes.
3. Mock correction and auto-tune pulses notified the simulated load cell in
   both `Grinder` and the calling controller, doubling simulated delivery.
4. Canceling auto-tune did not immediately stop an active motor pulse.
5. Verification could increment a candidate beyond the configured 300 ms
   maximum and then report success even though the value would not be saved.
6. Failure reporting said the default latency was used, while the stored
   previous latency was actually retained.

### Changes and rationale

- Split pulse duration into exact, non-looped RMT symbols and set the explicit
  end-of-transmission output level LOW.
- Store both finite and continuous RMT payloads in `Grinder`, preserving their
  lifetime for asynchronous transmission.
- Poll the RMT driver's transaction-completion state with a zero-timeout call
  instead of inferring completion from a GPIO read. (Superseded in stage 3 by
  the transmit-done callback, which does not log on every poll.)
- Reject zero or unsupported durations and leave grinder state inactive when
  encoder creation or transmission fails.
- Keep mock pulse notification in `Grinder`, the single hardware-abstraction
  owner.
- Stop an in-flight pulse immediately on auto-tune cancellation or failure.
- Enforce the configured auto-tune range before retrying, saving, or reporting
  success.
- Preserve and accurately report the previous latency on auto-tune failure.
- Handle the previously omitted priming state explicitly.

### Verification

- A host C++ regression check exhaustively verifies every requested duration
  from 0 through 1,000,000 microseconds, including all RMT boundaries.
- Production build 32 passed: RAM 67,752 bytes; flash 2,187,159 bytes.
- Debug build 33 passed: RAM 67,752 bytes; flash 2,274,999 bytes.
- Mock build 34 passed: RAM 67,808 bytes; flash 2,273,487 bytes.
- Source scan confirms one mock pulse notification call site, owned by
  `Grinder`.
- Stage cost versus baseline: 64 bytes RAM. The production flash increase is
  1,124 bytes.

## Stage 2: Grind-flow and calibration accuracy

### Findings

1. The default load-cell calibration factor is negative. Raw flow rates were
   sorted in ascending order before selecting the 95th percentile, but dividing
   by a negative factor reverses that order. A representative set therefore
   returned 1.00 g/s instead of the true calibrated 95th-percentile value of
   3.00 g/s. Underestimating flow can lengthen correction pulses and increase
   overshoot.
2. Calibration ran on the UI core but directly invoked an HX711 update while
   the sampling task owned the same bit-banged device on Core 0. The direct
   result was not used.
3. Tare and calibration cleared sample and noise rings on the UI core while
   Core 0 could append to them.
4. Calibration accepted an unsettled timeout, an empty sample set, and an
   implausibly small ADC delta as if it had succeeded. The UI advanced even
   when no valid factor was saved.
5. A blocking tare timeout left the request armed, allowing it to alter the
   zero point later after the UI had already reported completion.
6. Sample-window comparisons used absolute timestamp ordering. After the
   32-bit `millis()` counter rolled over, recent pre-rollover samples appeared
   newer than the current time and were excluded until the entire window had
   elapsed.

### Changes and rationale

- Select flow percentiles in calibrated-weight order. Positive calibration
  retains ascending raw order; negative calibration mirrors the selected raw
  index.
- Return zero flow for a zero or near-zero calibration factor rather than
  divide by it.
- Keep HX711 reads and tare-time ring resets on the Core 0 sampling task. The
  filter is re-seeded at the new tare point so readers do not observe an empty
  buffer or a false full-scale jump.
- Calibrate from the settled raw-filter snapshot and preserve raw history,
  which remains valid because it is stored in ADC units.
- Reject calibration when settling times out, no samples are available, the
  ADC delta is below the existing hardware threshold, or the calculated factor
  is invalid.
- Propagate tare and calibration failure to the UI operation wrapper. Failed
  operations keep the prior value, log the reason, and do not invoke the
  success transition.
- Disarm a timed-out blocking tare request.
- Replace absolute timestamp ordering with unsigned elapsed-time comparisons
  in flow, delta, min/max, sample-window, and SPS calculations.

### Verification

- A host regression verifies that both negative and positive calibration
  factors select 3.00 g/s from the representative flow-rate set and checks
  percentile index boundaries.
- A host regression verifies elapsed-time windows immediately across a
  `uint32_t` timestamp rollover.
- The Stage 1 exhaustive pulse-timing regression still passes.
- Final production build 39 passed: RAM 67,752 bytes; flash 2,189,671
  bytes.
- Final debug build 40 passed: RAM 67,752 bytes; flash 2,278,839 bytes.
- Final mock build 41 passed: RAM 67,808 bytes; flash 2,276,871 bytes.
- BLE host tests passed: 2 of 2.
- Python tool compilation and Git whitespace validation passed.
- Stage cost versus Stage 1: no additional RAM. The production flash increase
  is 2,512 bytes.

## Stage 3: Review follow-ups

A correctness review of stages 1 and 2 confirmed their fixes but found defects in and
around them.

### Findings

1. Cancelling auto-tune only set a deferred flag. `AutoTuneController::update()` is reached
   solely from `UIState::AUTOTUNING`, and the UI leaves that state on the same call stack, so
   the flag was never serviced. The controller stayed `is_running` and its log file stayed
   open, and every later `start()` was rejected as already running until reboot. Stage 1
   stopped the motor on cancel but left this half unfixed.
2. Polling `rmt_tx_wait_all_done()` with a zero timeout logs an ESP-IDF error on every
   unfinished poll. `libesp_driver_rmt.a` contains the `flush timeout` string,
   `CONFIG_LOG_DEFAULT_LEVEL` is `ERROR`, and nothing suppresses the `rmt` tag - roughly 27
   lines per 550 ms correction pulse at the 20 ms control interval, up to ten pulses per
   grind, and hundreds per auto-tune run.
3. The verification-failure console line still named the default latency after stage 1
   changed the behaviour to retain the previous one.
4. Stage 2 correctly stopped advancing the UI on a failed tare or calibration, but the
   overlay hides itself regardless, so the user saw it appear and vanish with the wizard on
   the same step and no explanation.
5. Encoding left a zero-duration second half in the final symbol, relying on the RMT treating
   that as an end marker - the assumption the pre-stage-1 short-pulse path avoided by writing
   a 1 us LOW.
6. The RMT payload capacity was derived from the auto-tune priming pulse while the motor test
   independently hardcoded the same 1,000 ms, and an out-of-range or failed transmission left
   `pulse_active` false, so callers read a pulse that never ran as one that had completed.
7. `tools/tests` was referenced by no build file, tool or workflow, so nothing compiled or ran
   the stage 1 and 2 regressions.
8. The blocking-tare timeout disarmed the request with a plain store, which can lose to a
   sampling-task pass already committing, and calibration inferred a settling timeout by
   comparing elapsed time against the timeout value.

### Changes and rationale

- Complete auto-tune cancellation synchronously inside `cancel()`, and remove the deferred
  flag that could never be serviced.
- Report pulse completion from the RMT transmit-done callback through an atomic flag, so the
  control loop makes no driver call and produces no driver logging.
- Report the retained latency on verification failure.
- Add a self-dismissing notice to `BlockingOperationOverlay` and an `on_failure` callback to
  the tare and calibration wrappers, used by the calibration wizard and the menu scale page.
- Spread pulse time evenly across symbols and across the halves within each symbol, so no
  half is zero-length for any pulse of at least 2 us and termination goes through the
  driver's end-of-transmission marker and the configured `eot_level`.
- Key the payload capacity off a dedicated maximum-pulse constant, assert at compile time that
  every caller fits, and return a result from `start_pulse_rmt()` so each caller can react.
- Add a `test` target to `tools/grinder.py` and a CI job that runs it on push and pull
  request.
- Claim the tare request with a compare-exchange on the sampling task, and return an explicit
  settling-timeout flag instead of inferring one from the elapsed time.

### Verification

- Host tests pass, 3 of 3, via `python3 tools/grinder.py test`. The pulse-timing regression
  additionally asserts, for every length up to 1,000,000 us, that no symbol half is
  zero-length and none exceeds the 15-bit hardware field.
- The runner was confirmed to fail and return a non-zero exit code when an assertion is
  inverted.
- Production build 50 passed: RAM 67,760 bytes; flash 2,191,127 bytes.
- Debug build passed: RAM 67,760 bytes; flash 2,281,011 bytes.
- Mock build passed: RAM 67,816 bytes; flash 2,278,739 bytes.
- Stage cost versus stage 2: 8 bytes RAM. The production flash increase is 1,456 bytes.

### Still requires hardware

- Scope the motor output for 30, 50, 100, 300, 550 and 1,000 ms pulses. The zero-duration
  dependency is gone, but the encoding remains the one part no host test can prove; the
  single-symbol lengths are the highest-value measurements.
- Cancel auto-tune during priming, then start it again immediately and confirm it runs.
- Confirm a disturbed tare and a calibration with no mass both show the failure notice and
  retain the previous zero and factor.

## Deliberately unchanged

- `-Ofast` remains enabled. No measured numerical or timing regression tied to
  it is available, so changing the global optimization mode would be
  speculative and performance-negative.
- The broader task architecture and controller interfaces remain unchanged.
- Filter constants, correction thresholds, and task rates remain unchanged.
  Without ground-truth hardware measurements, tuning them would be
  speculative and could reduce accuracy on real beans and grinders.

## On-device validation when hardware is available

- Scope the motor output for 30, 50, 100, 300, 550, and 1,000 ms pulses and
  compare HIGH time to the requested duration.
- Cancel auto-tune during its 1,000 ms priming pulse and confirm the motor
  output goes LOW immediately.
- Run mock auto-tune and manual correction flows to confirm one simulated mass
  increment per pulse.
- Complete several weighted grinds and compare final error, correction count,
  and recorded flow rate with the prior firmware.
- Tare repeatedly under both quiet and noisy conditions; verify failed/timeout
  attempts retain the previous zero and successful attempts settle near zero.
- Calibrate with the reference mass several times; verify factors are
  repeatable, polarity is preserved, and unstable/missing masses do not save.
- Leave a unit running across the `millis()` rollover (approximately 49.7
  days), or inject timestamps around rollover in a hardware test build, and
  confirm flow/SPS telemetry remains continuous.

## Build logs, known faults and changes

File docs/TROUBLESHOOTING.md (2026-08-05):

# Troubleshooting Guide

## Table of Contents

- [Motor Does Not Start](#motor-does-not-start)
- [HX711 Not Detected / Wrong Sample Rate](#hx711-not-detected--wrong-sample-rate)
- [Unknown board ID 'esp32-s3-devkitc-1'](#unknown-board-id-esp32-s3-devkitc-1)
- [PlatformIO Project Initialization Issues](#platformio-project-initialization-issues)
- [Grind Timeout Screen](#grind-timeout-screen)
- [Unreliable Pulse Corrections](#unreliable-pulse-corrections)
- [Unexplained Reboots](#unexplained-reboots)
- [Getting Diagnostic Reports](#getting-diagnostic-reports)

---

## Motor Does Not Start

**Applies to:** Eureka Mignon installations where the grinder motor does not activate when commanded.

### Symptoms
- Motor test function (Menu → Motor Test) does not start the motor
- GRIND button does not start the motor
- All other functionality works normally (screen, weight readings, etc.)

**Note:** If you hear a click and humming sound but no coffee grounds come out, the motor **is** starting correctly - your grinder is clogged, not a wiring issue.

### Root Cause
The motor control wire (Pin 3) and button signal wire (Pin 2) from the Eureka 4-pin plug may be reversed on the Waveshare board connection. The button signal wire does not control the motor.

### Diagnosis

**Option 1: Use Motor Test Function (Recommended)**

Access **Menu → Motor Test** (Tools section) to verify motor connectivity. This button activates the motor for a short test pulse. If the motor does not run during the test, the motor wire is incorrectly connected.

**Option 2: Manual Wire Identification (Advanced - Use with Extreme Caution)**

⚠️ **DANGER:** This test involves live wires and can cause the grinder to start unexpectedly, potentially causing injury or damage. Only attempt if comfortable working with electrical systems.

Using the 4-pin Eureka plug pinout (see `../media/4-pin_Eureka_plug_pinout.png` in documentation):
- **Pin 1**: 5V power supply
- **Pin 2**: Button signal (unused in this project)
- **Pin 3**: Motor control signal *(active-high — motor engages when driven to 3.3-5V)*
- **Pin 4**: Ground

The motor control wire (Pin 3) is the wire that **starts the motor when briefly driven HIGH (touch it to Pin 1 / 5V)**. Test carefully:
1. Ensure grinder is powered and hopper has minimal beans
2. Disconnect the suspect wire from the Waveshare board
3. Briefly touch the wire to 5V (Pin 1) - motor should start
4. **Be prepared for the powerful motor to cause the grinder to twist/jump**
5. **Avoid shorts that could damage the board or cause injury**

### Resolution

**Swap the wire connections:**
- The motor control wire (Pin 3) should connect to Waveshare **GPIO 18**
- The button signal wire (Pin 2) can remain disconnected (unused in this project)

If wires were reversed, swap them so Pin 3 connects to GPIO 18. The Waveshare board has reverse polarity protection for power connections, but the motor/button wires should be correctly identified for proper operation.

**Important:** Wire colors vary significantly between Eureka units - always refer to pin positions rather than wire colors when troubleshooting.

---

## HX711 Not Detected / Wrong Sample Rate

**Applies to:** First-boot issues when the load cell board is missing, miswired, or strapped for 80 SPS.

### Symptoms
- Startup log shows `HX711_NOT_CONNECTED` or `HX711_SAMPLE_RATE_INVALID`.
- Weight display stays at `0.00 g`; grinding and calibration remain disabled.

### Quick Fixes
- **NOT_CONNECTED:** Verify VCC/GND/SCK/DOUT wiring and that the HX711 board is powered.
- **SAMPLE_RATE_INVALID:** Ensure the HX711 `RATE` pin is tied to GND for 10 SPS; a floating/high pin forces 80 SPS and will now block startup.
- After correcting hardware, reboot the scale. The diagnostic clears automatically when healthy samples are detected.

## Load Cell Signal Saturated

**Applies to:** HX711 communicates but the reading is pegged at a rail (raw ADC 16777215 or 0).

### Symptoms
- Warning icon (⚠) with message "Load cell signal saturated. Check A+/A- signal wiring."
- Raw ADC reading stuck at 16777215 (0xFFFFFF) or 0, unchanged when pressing on the load cell.
- The grind button does nothing in weight mode - grinds are refused while the diagnostic is active because there is no usable weight feedback. Time mode still grinds normally.

### Root Cause
The HX711 amplifier input is railed - the differential signal exceeds the ±20mV input range at gain 128. This is an electrical fault, not a firmware or calibration issue.

### Quick Fixes
- **Broken/disconnected signal wire:** Check continuity of the A+ and A- (green/white) wires from load cell to HX711.
- **Swapped wires:** Verify excitation (E+/E-, typically red/black) and signal (A+/A-, typically green/white) wires are not crossed. Measure A+ to A-: it should read single-digit millivolts, not volts.
- **Damaged load cell:** With correct wiring, A+ to A- should change by a few mV when load is applied. If it stays railed, replace the cell.
- The diagnostic clears automatically once healthy readings return.

## Unknown board ID 'esp32-s3-devkitc-1'

**Applies to:** Windows development environments using PlatformIO with ESP32-S3 boards.

### Symptoms
- `platformio run` fails with `UnknownBoard: Unknown board ID 'esp32-s3-devkitc-1'`.
- `pio boards espressif32 | findstr "esp32-s3"` shows the board, suggesting it exists in the registry.

### Root Cause
The local PlatformIO `espressif32` platform package was pinned to an older release (e.g. 3.1.0 from 2021) that predates ESP32-S3 board definitions. The registry lookup reports current boards, but the outdated local package lacks the corresponding JSON definition.

### Resolution
1. Update the global `espressif32` platform package so it includes ESP32-S3 board definitions:
   ```powershell
   C:\Users\<user>\.platformio\penv\Scripts\platformio.exe pkg install -g -p platformio/espressif32@^6.8.0
   ```
   *(Alternatively, run `pio platform update espressif32`.)*
2. Re-run the build:
   ```powershell
   C:\Users\<user>\.platformio\penv\Scripts\platformio.exe run
   ```
3. Optional: Pin the desired platform version in `platformio.ini` to ensure consistency across machines:
   ```ini
   [env:waveshare-esp32s3-touch-amoled-164]
   platform = platformio/espressif32@^6.8.0
   ```

### Notes
- The warning `Ignore unknown configuration option 'monitor_options'` also disappears once PlatformIO core and platform packages are current.
- If multiple PlatformIO installations are present, ensure you are updating the instance used for the project.

---

## PlatformIO Project Initialization Issues

**Applies to:** General PlatformIO project setup issues, especially when using PlatformIO (as this project uses the pioarduino fork as a platform).

### Symptoms
- `Error: Could not find one of 'package.json' manifest files in the package`
- PlatformIO fails to initialize the project properly
- Vague platform-related errors during project setup

### Root Cause
The use of the pioarduino platform fork can sometimes cause PlatformIO's cache or project state to become inconsistent, leading to initialization failures.

### Resolution
1. **Close VS Code completely**
2. **Delete the PlatformIO cache folder:**
   ```bash
   # On Windows
   rmdir /s "%USERPROFILE%\.platformio"
   
   # On macOS/Linux  
   rm -rf ~/.platformio
   ```
3. **Restart VS Code**
4. **Reopen the project** - PlatformIO will reinitialize and download the correct platform packages
5. **Perform a clean build** - Use PlatformIO's "Clean" then "Build" to ensure a fresh compilation

### Alternative (Less Nuclear)
If you want to try a less aggressive approach first:
1. Close VS Code
2. Delete only the platforms cache: `~/.platformio/platforms/` (or `%USERPROFILE%\.platformio\platforms\` on Windows)
3. Restart VS Code and reopen project
4. Perform a clean build in PlatformIO

**Note:** This issue is specific to the pioarduino platform fork usage and the way PlatformIO handles custom platform URLs.

---

## Grind Timeout Screen

**Applies to:** Grinder timing out during operation, showing timeout screen after 30 seconds.

### Symptoms
- Grinder reaches timeout screen during grinding cycle
- Long taring process (>10 seconds)
- Unstable weight readings

### Root Cause
Extended taring due to load cell noise prevents grinding from completing within 30-second limit.

### Diagnosis
Check **Menu → Diagnostics → "Noise Floor"** section (see [Diagnostics System](DOC.md#diagnostics-system) for details). If "Noise level: Too High" (red text) appears persistently, your load cell has sustained noise issues that will cause slow taring (>2 seconds). A warning icon (⚠) will appear in the top-right corner when sustained noise is detected.

### Resolution
1. **Check load cell wiring:**
   - Verify shielding wire connection per wiring diagram
   - Shorten load cell cables if possible
   - Ensure clean, solid connections

2. **Check calibration factor (reference examples only):**

   Calibration factors vary between individual load cells, but extreme deviations may indicate hardware issues. Check your calibration factor in **Menu → Diagnostics → Load Cell Status**. Example values from tested units:
   - **1KG T70 load cell**: ±4400 (example)
   - **0.3KG Mavin Load Cell**: ±6580 (example)

   **Note:** These are examples only and can differ significantly between load cells. Use them as rough reference points, not expected values.

3. **If wiring issues persist:**
   - Increase `GRIND_SCALE_SETTLING_TOLERANCE_G` parameter for more noise tolerance

---

## Unreliable Pulse Corrections

**Applies to:** Pulse corrections failing to produce grounds consistently, requiring multiple correction cycles.

### Symptoms
- Multiple pulse attempts needed to reach target weight
- Inconsistent grounds production during pulse phase
- Overshooting or undershooting target weight frequently

### Root Cause
Motor response latency mismatch between firmware settings and actual hardware characteristics. Default 50ms may not match your specific grinder's relay type (solid-state vs mechanical), voltage (110V vs 220V), or burr inertia.

### Resolution

**Recommended:** Use the Auto-Tune Motor Response feature to automatically calibrate optimal pulse duration for your hardware:

1. **Access auto-tune**: Menu → Tune Pulses (Tools section)
2. **Prepare system**:
   - Ensure beans are in hopper
   - Place dosing cup on scale
   - System will automatically tare
3. **Run calibration**: Process takes 1-2 minutes
   - Priming phase: 500ms pulse to position beans
   - Binary search: Finds minimum reliable pulse duration
   - Verification: Confirms 80%+ success rate across 5 test pulses
4. **Check result**: New motor latency value displayed on completion
   - Typical range: 30-200ms depending on hardware
   - Value saved automatically to device preferences
   - Displayed in **Menu → Diagnostics**

**Verify calibration**: Check **Menu → Diagnostics → Motor Latency** to see current value. Re-run auto-tune if you change grinders, modify relay hardware, or continue experiencing unreliable pulse corrections.

**Manual fallback:** If auto-tune fails, system reverts to safe 50ms default. Check grinder power connection, hopper bean level, and scale setup.

---

## Unexplained Reboots

**Applies to:** The screen blanks and the grinder restarts on its own, with or without a noise from the grinder.

### Diagnosis

Pull a diagnostic report and read `[BOOT HISTORY]`. It records the last 8 boots and what the device was doing when each one ended:

```
[BOOT HISTORY]
  This boot started with: BROWNOUT
  Previous boot died in: BREW_ENTRY / grind IDLE / cloud sync session upload
    after 94s up, 9224 B internal free (8468 B min), build #100501
  2026-08-06 07:52:55  #100501  BROWNOUT   ran 0h 08m 46s (this boot)
  2026-08-04 17:49:22  #100501  SW         ran 38h 03m 33s
```

The reset kind is the fork in the road:

| Kind | Meaning |
|---|---|
| `BROWNOUT` | The supply sagged below the detector threshold. A power problem, not firmware. |
| `PANIC` | The firmware hit an exception. |
| `TASK_WDT` / `INT_WDT` / `WDT` | A task stopped feeding its watchdog. |
| `SW` | A deliberate restart — an OTA update, or a boot-guard rollback. |
| `POWER_ON` | Cold start. On a grinder nobody unplugged, a sag deep enough to drop the RTC domain reads this way. |
| `EXT_PIN` | The reset pin was pulled. |

The `Previous boot died in` line narrows it further, because the two largest current draws in the system are both visible there: `grind PREDICTIVE` or `PULSE_EXECUTE` means the motor was running, and `cloud sync` anything other than `idle` means the WiFi radio was up and transmitting. A brownout that only ever lands on one of those points at the supply rather than the firmware.

`B internal free` is the other half. Internal DRAM is what LVGL, the BLE stack and WiFi station init all draw from; a `min` figure in the single-digit KB with a `PANIC` beside it is heap exhaustion, not a power fault.

### Resolution

**If the kind is `BROWNOUT` or `POWER_ON`:**
- Check what the ESP32 is powered from. Tapping the grinder's own supply works only if that rail can carry WiFi TX bursts (~350 mA peaks) on top of the relay coil.
- Add bulk capacitance across the 5 V input, or move the board to its own supply.
- A large negative weight excursion in a grind log (a dive to −90 g or so, tripping the negative-weight failsafe) is the same fault seen through the HX711: its output is ratiometric, so a sagging excitation reads as a huge negative weight. Those aborted grinds and the reboots usually share one cause.

**If the kind is `PANIC` or a watchdog:** it is a firmware fault. Include the whole `[BOOT HISTORY]` block in a GitHub issue — the state, phase and heap figures are what make it reproducible.

**Note:** a reset while the shot log is on screen no longer loses the shot. The prompt is written to NVS while it is displayed and comes back after the reboot, so the yield and time can still be entered. A clean power-on retires it instead of restoring a stale prompt.

---

## Getting Diagnostic Reports

**Applies to:** Reporting issues on GitHub or troubleshooting system behavior.

### What is a Diagnostic Report?

The diagnostic report is a comprehensive text dump of your device's current state, including:
- Firmware version, build number, and git commit
- Boot history: why each of the last 8 boots happened, and what the device was doing when the previous one ended
- System information (uptime, CPU frequency, RAM, flash storage)
- All compile-time constants (grind settings, thresholds, timeouts)
- Runtime statistics (lifetime grinds, total weight)
- Load cell calibration status and noise diagnostics
- Motor latency settings
- Autotune results (if available)

This information helps identify configuration issues, hardware problems, or firmware bugs.

### How to Get a Diagnostic Report

#### Option 1: Web Flasher (Recommended)

1. Visit the **[Web Flasher Diagnostics Tool](https://coffeegrinder.preetpatel.com)**
2. Click the **"Diagnostics"** tab
3. Click **"Connect & Get Diagnostics"**
4. Select your device from the Bluetooth pairing dialog
5. Wait for the report to complete (~5-10 seconds)
6. Click **"Copy to Clipboard"** or **"Download Report"**
7. Paste the report into your GitHub issue

**Browser Requirements:** Chrome, Edge, or Opera on desktop/Android (Web Bluetooth API required)

#### Option 2: Command Line Tool

If you have the development environment set up:

```bash
# Get diagnostics and display in terminal
python3 tools/grinder.py diagnostics

# Save diagnostics to a file
python3 tools/grinder.py diagnostics --save diagnostics.txt
```

### When to Include a Diagnostic Report

**Always include a diagnostic report when reporting:**
- Grinding accuracy issues (overshooting/undershooting)
- Timeout errors or slow taring
- Load cell calibration problems
- Motor response issues
- Any unexpected behavior or crashes
- Feature requests that depend on your hardware configuration

**The diagnostic report is anonymous** and contains no personal information. It only includes technical device settings and statistics.

### Including Grind Results in Your Report

**For grind-related issues, follow these steps before generating the diagnostic report:**

1. **Enable logging:** Menu → Data → Enable Logging
2. **Reproduce the issue:** Perform at least one grind where the issue occurs
3. **Generate diagnostics:** Use one of the methods above (Web Flasher or Command Line)

The diagnostic report will automatically include your recent grind session data, which is essential for troubleshooting accuracy issues, pulse corrections, timeout problems, and other grind behavior issues. Without recent grind data, it's much harder to diagnose what's going wrong.

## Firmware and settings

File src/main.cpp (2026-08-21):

#include <Arduino.h>
#include <LittleFS.h>
#include <Preferences.h>
#include <esp_system.h>
#include <esp_heap_caps.h>
#include "hardware/hardware_manager.h"
#include "system/boot_guard.h"
#include "system/boot_history.h"
#include "system/state_machine.h"
#include "system/statistics_manager.h"
#include "system/time_sync.h"
#include "system/wifi_service.h"
#include "system/cloud_sync.h"
#include "system/bean_config.h"
#include "system/brew_log.h"
#include "system/last_shot.h"
#include "controllers/profile_controller.h"
#include "controllers/grind_controller.h"
#include "ui/ui_manager.h"
#include "config/constants.h"
#include "bluetooth/manager.h"
#include "tasks/task_manager.h"
#include "tasks/weight_sampling_task.h"
#include "tasks/grind_control_task.h"
#include "tasks/file_io_task.h"

HardwareManager hardware_manager;
StateMachine state_machine;
ProfileController profile_controller;
GrindController grind_controller;
UIManager ui_manager;
BluetoothManager g_bluetooth_manager;
BluetoothManager& bluetooth_manager = g_bluetooth_manager;

#if SYS_ENABLE_REALTIME_HEARTBEAT
// Core 1 timing metrics (global scope for main loop access)
static uint32_t core1_cycle_count_10s = 0;
static uint32_t core1_cycle_time_sum_ms = 0;
static uint32_t core1_cycle_time_min_ms = UINT32_MAX;
static uint32_t core1_cycle_time_max_ms = 0;
static uint32_t core1_last_heartbeat_time = 0;
#endif

void setup() {
    Serial.begin(HW_SERIAL_BAUD_RATE);
#ifdef UI_DEBUG_SERIAL_DELAY_MS
    delay(UI_DEBUG_SERIAL_DELAY_MS);
#endif
    
    // Records why this boot happened and recovers the previous boot's black
    // box, both of which reach the user over BLE in the diagnostics report.
    // Runs before the boot guard, which may reboot into the other OTA slot.
    BootHistory::init();

    // Boot-loop guard: after 3 consecutive crash resets, revert to the other
    // OTA slot. Runs before any subsystem that could be the crash source.
    BootGuard::check_on_boot();

    // Memory census before anything allocates. LVGL, Bluedroid and the widget tree all draw from
    // the internal heap, so if PSRAM is missing here every large buffer falls back to internal
    // DRAM and the device runs out. PSRAM totals of 0 mean the board is not mapping it at all.
    LOG_BLE("[STARTUP] Internal heap: %u free / %u total | PSRAM: %u free / %u total\n",
            (unsigned)heap_caps_get_free_size(MALLOC_CAP_INTERNAL),
            (unsigned)heap_caps_get_total_size(MALLOC_CAP_INTERNAL),
            (unsigned)heap_caps_get_free_size(MALLOC_CAP_SPIRAM),
            (unsigned)heap_caps_get_total_size(MALLOC_CAP_SPIRAM));


    // Early startup heartbeat - helps capture initialization sequence
    LOG_BLE("[STARTUP] Initializing ESP32-S3 Coffee Scale - Build %d - Core1 active\n", BUILD_NUMBER);
    
    // Initialize LittleFS once - format if necessary
    if (!LittleFS.begin(true)) {
        LOG_BLE("ERROR: LittleFS mount failed - continuing without filesystem\n");
    } else {
        LOG_BLE("✅ LittleFS mounted successfully\n");
    }
    
    hardware_manager.init();

    // Clock display style (12/24 hour) - needed before the first UI frame
    TimeSync::init();

    profile_controller.init(hardware_manager.get_preferences());
    statistics_manager.init(hardware_manager.get_preferences());
    grind_controller.init(hardware_manager.get_load_cell(), hardware_manager.get_grinder(), hardware_manager.get_preferences());
    
    // Set up the reference so HardwareManager can query GrindController state
    hardware_manager.set_grind_controller(&grind_controller);
    
    bluetooth_manager.init(hardware_manager.get_preferences());

    // Loads stored WiFi credentials + TZ rule and schedules the boot-time
    // SNTP sync (runs from loop(); no-op until credentials are provisioned)
    wifi_service.init(&grind_controller, &bluetooth_manager);

    // Cloud session sync rides inside WifiService windows; no-op until a
    // store is provisioned over BLE (docs/CLOUD_SYNC.md)
    cloud_sync.init();

    // Active bean cache (BLE push / cloud fetch) and the queue of brew
    // records awaiting upload. Both no-ops until a bean is provisioned.
    bean_config.init();
    brew_log.init();

    // What the last grind delivered, for the ready-screen chip.
    last_shot.init();

    // Check for OTA failure to determine initial state
    String failed_ota_build = bluetooth_manager.check_ota_failure_after_boot();
    bool ota_failed = !failed_ota_build.isEmpty();

    // Check calibration status to determine initial screen
    bool is_calibrated = hardware_manager.get_weight_sensor()->is_calibrated();

    if (ota_failed) {
        LOG_BLE("BOOT: Starting in OTA failure state for expected build %s\n", failed_ota_build.c_str());
        state_machine.init(UIState::OTA_UPDATE_FAILED);
    } else if (!is_calibrated) {
        LOG_BLE("BOOT: Device not calibrated - starting in CALIBRATION state\n");
        state_machine.init(UIState::CALIBRATION);
    } else {
        state_machine.init(UIState::READY);
    }
    
    ui_manager.init(&hardware_manager, &state_machine, &profile_controller, &grind_controller, &bluetooth_manager);
    
    // Store OTA failure info in ui_manager if needed
    if (ota_failed) {
        if (auto* ota = ui_manager.get_ota_data_export_controller()) {
            ota->set_failure_info(failed_ota_build.c_str());
        }
    }

    // A reset mid-shot must not take the unanswered shot log with it. Skipped
    // where the boot already owes the user a different screen.
    if (!ota_failed && is_calibrated) {
        ui_manager.restore_brew_prompt();
    }
    
    // Set up UI status callback to avoid circular dependency
    bluetooth_manager.set_ui_status_callback([](const char* status) {
        if (auto* ota = ui_manager.get_ota_data_export_controller()) {
            ota->update_status(status);
        }
    });
    
    // Enable BLE by default during bootup with 2-minute timeout
    // (Previously disabled by default for security, now enabled for user convenience)
    bluetooth_manager.enable_during_bootup();
    
    // Initialize individual task modules BEFORE TaskManager creates FreeRTOS tasks
    // This ensures all task dependencies are ready before tasks start running
    LOG_BLE("[STARTUP] Initializing task module dependencies...\n");
    weight_sampling_task.init(hardware_manager.get_load_cell(), &grind_logger);
    grind_control_task.init(&grind_controller, hardware_manager.get_load_cell(), 
                           hardware_manager.get_grinder(), &grind_logger);
    
    LOG_BLE("✅ Task module dependencies initialized\n");
    
    // Initialize TaskManager with hardware and system interfaces
    LOG_BLE("[STARTUP] Initializing FreeRTOS Task Architecture...\n");
    bool task_init_success = task_manager.init(&hardware_manager, &state_machine, &profile_controller, 
                                              &grind_controller, &bluetooth_manager, &ui_manager);
    
    if (!task_init_success) {
        LOG_BLE("ERROR: Failed to initialize TaskManager - system cannot start\n");
        while (true) {
            delay(1000); // Halt system if task initialization fails
        }
    }
    
    LOG_BLE("✅ TaskManager initialized successfully\n");
    
    // Initialize remaining task modules that depend on TaskManager queues
    file_io_task.init(task_manager.get_file_io_queue());
    
    LOG_BLE("✅ All task modules initialized\n");
}

void loop() {


#if SYS_ENABLE_REALTIME_HEARTBEAT
    // Core 1 main loop timing (monitor main loop health)
    uint32_t cycle_start_time = millis();
    core1_cycle_count_10s++;
    if (core1_last_heartbeat_time == 0) core1_last_heartbeat_time = cycle_start_time;
#endif

    // Update device uptime statistics every 15 minutes, reporting back in hours
    static uint32_t last_uptime_update = 0;
    static uint32_t pending_uptime_minutes = 0;
    uint32_t current_time = millis();
    if (last_uptime_update == 0) {
        last_uptime_update = current_time;
    }
    constexpr uint32_t kUptimeIntervalMs = 900000; // 15 minutes
    constexpr uint32_t kUptimeIntervalMinutes = 15;
    uint32_t elapsed_ms = current_time - last_uptime_update;
    if (elapsed_ms >= kUptimeIntervalMs) {
        uint32_t intervals = elapsed_ms / kUptimeIntervalMs;
        pending_uptime_minutes += intervals * kUptimeIntervalMinutes;
        last_uptime_update += intervals * kUptimeIntervalMs;

        if (pending_uptime_minutes > 0) {
            statistics_manager.update_uptime(pending_uptime_minutes);
            pending_uptime_minutes = 0;
        }
    }
    
    // Check OTA state and suspend hardware tasks if needed
    static bool hardware_suspended = false;
    bool ota_active = bluetooth_manager.is_updating();
    
    if (ota_active && !hardware_suspended) {
        task_manager.suspend_hardware_tasks();
        hardware_suspended = true;
        LOG_BLE("[MAIN] Hardware tasks suspended for OTA\n");
    } else if (!ota_active && hardware_suspended) {
        task_manager.resume_hardware_tasks();
        hardware_suspended = false;
        LOG_BLE("[MAIN] Hardware tasks resumed after OTA\n");
    }
    
    // UI events are now processed inside the UI render FreeRTOS task
    // to serialize all LVGL updates on a single thread.

    // Duty-cycled WiFi time sync; gates itself off grind/OTA/export activity
    wifi_service.handle();

    // Keep the crash black box current: whatever the device was doing on this
    // pass is what the next boot reports if this one doesn't survive.
    BootHistory::note_activity((uint8_t)state_machine.get_current_state(),
                               grind_controller.get_current_phase_id(),
                               cloud_sync.get_run_phase_id());

    // Clear the boot-loop crash counter once the system has proven stable
    BootGuard::mark_healthy_if_due();

#if DEBUG_BOOT_GUARD_DRILL
    // Rollback drill: panic ~5s after boot - after the guard has counted
    // (setup) and before the 30s healthy mark - so three cycles trip the
    // crash rollback. The independent drill counter is the parachute: if
    // the guard never fires, boot 5 disarms and the device stays reachable.
    {
        static bool drill_fired = false;
        if (!drill_fired && millis() > 5000) {
            drill_fired = true;
            Preferences drill_prefs;
            if (drill_prefs.begin("bootguard", false)) {
                uint8_t drill_boots = drill_prefs.getUChar("drill_boots", 0);
                if (drill_boots < 4) {
                    drill_prefs.putUChar("drill_boots", drill_boots + 1);
                    drill_prefs.end();
                    LOG_BLE("[BOOT_GUARD_DRILL] Drill boot %u - forcing panic\n", drill_boots + 1);
                    delay(200);
                    abort();
                }
                drill_prefs.end();
                LOG_BLE("[BOOT_GUARD_DRILL] Disarmed after %u boots - guard never fired, rescue via OTA\n",
                        drill_boots);
            }
        }
    }
#endif

#if SYS_ENABLE_REALTIME_HEARTBEAT
    // Calculate Core 1 main loop timing
    uint32_t cycle_end_time = millis();
    uint32_t cycle_duration = cycle_end_time - cycle_start_time;
    core1_cycle_time_sum_ms += cycle_duration;
    if (cycle_duration < core1_cycle_time_min_ms) core1_cycle_time_min_ms = cycle_duration;
    if (cycle_duration > core1_cycle_time_max_ms) core1_cycle_time_max_ms = cycle_duration;
    
    // Core 1 Main Loop Heartbeat - Monitor main loop health (every 10 seconds)
    if (cycle_end_time - core1_last_heartbeat_time >= SYS_REALTIME_HEARTBEAT_INTERVAL_MS) {
        uint32_t avg_cycle_time = core1_cycle_count_10s > 0 ? core1_cycle_time_sum_ms / core1_cycle_count_10s : 0;
        
        // Get system states
        bool is_grinding = grind_controller.is_active();
        const char* ble_state = bluetooth_manager.is_enabled() ? 
                               (bluetooth_manager.is_connected() ? "CONN" : "ADV") : "OFF";
        const char* grinder_state = is_grinding ? "ACTIVE" : "IDLE";
        const char* tasks_status = task_manager.are_tasks_healthy() ? "HEALTHY" : "ERROR";
        size_t free_heap_kb = ESP.getFreeHeap() / 1024;

        // Internal heap detail: a steadily falling "free" is a leak, a low but stable "free" with
        // a much smaller "largest block" is fragmentation, and "min" is the worst it has ever
        // been - the number that actually predicts the next failed allocation.
        size_t internal_free = heap_caps_get_free_size(MALLOC_CAP_INTERNAL);
        size_t internal_min = heap_caps_get_minimum_free_size(MALLOC_CAP_INTERNAL);
        size_t internal_largest = heap_caps_get_largest_free_block(MALLOC_CAP_INTERNAL);
        size_t psram_free = heap_caps_get_free_size(MALLOC_CAP_SPIRAM);

        LOG_BLE("[%lums MAIN_LOOP_HEARTBEAT] Cycles: %lu/10s | Avg: %lums (%lu-%lums) | Tasks: %s | BLE: %s | Grinder: %s | Mem: %zuKB | Int: %zu free/%zu min/%zu largest | PSRAM: %zu | Build: #%d\n",
               millis(), core1_cycle_count_10s, avg_cycle_time, core1_cycle_time_min_ms, core1_cycle_time_max_ms,
               tasks_status, ble_state, grinder_state, free_heap_kb,
               internal_free, internal_min, internal_largest, psram_free, BUILD_NUMBER);
        
        // Reset Core 1 metrics for next interval
        core1_cycle_count_10s = 0;
        core1_cycle_time_sum_ms = 0;
        core1_cycle_time_min_ms = UINT32_MAX;
        core1_cycle_time_max_ms = 0;
        core1_last_heartbeat_time = cycle_end_time;
    }
#endif
    
    // The main loop now runs much lighter since FreeRTOS tasks handle all the heavy work
    // Just yield to allow FreeRTOS scheduler to run other tasks efficiently
    vTaskDelay(pdMS_TO_TICKS(10)); // Small delay to prevent starving other tasks
}

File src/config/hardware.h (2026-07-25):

#pragma once

//==============================================================================
// HARDWARE CONFIGURATION CONSTANTS
//==============================================================================
// This file contains hardware-specific configuration values that define the
// physical characteristics and constraints of the ESP32-S3 coffee grinder system.
// These values are tied to the specific hardware implementation and should only
// be modified when changing hardware components.

//------------------------------------------------------------------------------
// GPIO PIN ASSIGNMENTS
//------------------------------------------------------------------------------
// Touch Controller (I2C)
#define HW_TOUCH_I2C_SDA_PIN 47                                                // I2C data pin for capacitive touch controller
#define HW_TOUCH_I2C_SCL_PIN 48                                                // I2C clock pin for capacitive touch controller
#define HW_TOUCH_I2C_ADDRESS 0x38                                              // I2C address of FT3168 touch controller

// Display Controller (QSPI)
#define HW_DISPLAY_CS_PIN 9                                                    // SPI chip select for display controller
#define HW_DISPLAY_SCK_PIN 10                                                  // SPI clock for display controller
#define HW_DISPLAY_D0_PIN 11                                                   // SPI data line 0 (QSPI mode)
#define HW_DISPLAY_D1_PIN 12                                                   // SPI data line 1 (QSPI mode)
#define HW_DISPLAY_D2_PIN 13                                                   // SPI data line 2 (QSPI mode)
#define HW_DISPLAY_D3_PIN 14                                                   // SPI data line 3 (QSPI mode)
#define HW_DISPLAY_RESET_PIN 21                                                // Display reset pin

// Load Cell ADC Pins
#define HW_LOADCELL_DOUT_PIN 3                                                 // HX711 data output pin
#define HW_LOADCELL_SCK_PIN 2                                                  // HX711 serial clock pin

// Motor Control
#define HW_MOTOR_RELAY_PIN 18                                                  // GPIO pin for grinder motor control relay
#define HW_GRINDER_SETTLING_TIME_MS 500                                        // Startup transient immunity (tune based on mechanical rigidity, 0 to disable)

//------------------------------------------------------------------------------
// LOAD CELL ADC SPECIFICATIONS
//------------------------------------------------------------------------------
// Sample rate configuration
#define HW_LOADCELL_SAMPLE_RATE_SPS 10                                         // Current sample rate setting
#define HW_LOADCELL_SAMPLE_INTERVAL_MS (1000 / HW_LOADCELL_SAMPLE_RATE_SPS)   // Calculated sample interval

// Calibration validation
#define HW_LOADCELL_CAL_MIN_ADC_VALUE 1000                                    // Minimum ADC value to confirm weight placed on scale

// Saturation detection (ADC input pegged at a rail => wiring/electrical fault)
// Normalized 24-bit range is 0x000000..0xFFFFFF; a saturated HX711 clips to a rail.
#define HW_LOADCELL_SATURATION_MARGIN_ADC 1000                                // Samples within this margin of either rail count as saturated
#define HW_LOADCELL_SATURATION_SAMPLE_COUNT 10                                // Consecutive saturated samples before flagging (~1s at 10 SPS)

//------------------------------------------------------------------------------
// DISPLAY SPECIFICATIONS  
//------------------------------------------------------------------------------
#define HW_DISPLAY_WIDTH_PX 280                                                // LCD width in pixels
#define HW_DISPLAY_HEIGHT_PX 456                                               // LCD height in pixels
#define HW_DISPLAY_OFFSET_X_PX 0                                               // X offset for display positioning
#define HW_DISPLAY_ROTATION_DEG 0                                              // Display rotation angle
#define HW_DISPLAY_IPS_INVERT_X 180                                            // IPS X-axis inversion setting
#define HW_DISPLAY_IPS_INVERT_Y 24                                             // IPS Y-axis inversion setting
#define HW_DISPLAY_COLOR_ORDER 20                                              // Color channel ordering
#define HW_DISPLAY_MINIMAL_BRIGHTNESS_PERCENT 15                               // Minimum brightness percentage (to avoid too dim to see)

//------------------------------------------------------------------------------
// SERIAL COMMUNICATION
//------------------------------------------------------------------------------
#define HW_SERIAL_BAUD_RATE 115200                                             // UART baud rate for debug/logging output

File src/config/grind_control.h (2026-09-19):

#pragma once

//==============================================================================
// GRIND CONTROL CONFIGURATION
//==============================================================================
// This file contains all grind control related configuration constants
// including timing parameters, accuracy settings, flow detection, and
// pulse control algorithms.

//------------------------------------------------------------------------------
// GRINDER PURGE/PRIME
//------------------------------------------------------------------------------
// Grinder saturation modes
enum class GrinderPurgeMode {
    PRIME = 0,  // Saturate grinder, keep coffee, continue immediately
    PURGE = 1   // Saturate grinder, prompt user to discard stale grinds
};

// Grinder saturation defaults and ranges
#define GRIND_PURGE_MODE_DEFAULT static_cast<int>(GrinderPurgeMode::PURGE)
#define GRIND_PURGE_AMOUNT_DEFAULT_G 1.0f
#define GRIND_PURGE_AMOUNT_MIN_G 0.1f
#define GRIND_PURGE_AMOUNT_MAX_G 2.5f

// Grind freshness tracking
#define GRIND_FRESHNESS_DEFAULT_HOURS 8.0f

//------------------------------------------------------------------------------
// GRIND CONTROL TUNING
//------------------------------------------------------------------------------
// Main accuracy and timeout settings
#define GRIND_ACCURACY_TOLERANCE_G 0.03f                                  // Final target accuracy tolerance
#define GRIND_TIMEOUT_SEC 60                                              // Maximum time for grind operation
#define GRIND_SCALE_STALE_SAMPLE_TIMEOUT_MS 1000                          // Abort if the load cell stops delivering samples this long mid-grind (10 missed at 10 SPS; a supply sag at motor start stalls it for ~0.5s and recovers)
#define GRIND_MAX_PULSE_ATTEMPTS 10                                       // Maximum pulse corrections before stopping

// Flow rate detection
#define GRIND_FLOW_DETECTION_THRESHOLD_GPS 0.5f                           // Minimum coffee flow rate to establish first grinds reachinig the cup = latency

// Undershoot strategy - determine when to stop grinding during the predictive phase
#define GRIND_UNDERSHOOT_TARGET_G 1.0f                                    // Default conservative undershoot target
#define GRIND_LATENCY_TO_COAST_RATIO 1.0f                                 // Ratio of expected coast time to measured latency (e.g., 0.8 = 80%)

// Prime phase behavior
#define GRIND_PRIME_TARGET_WEIGHT_G 1.0f                                   // Amount of coffee delivered during chute priming
#define GRIND_PRIME_MAX_DURATION_MS 5000                                   // Safety timeout for chute priming run
#define GRIND_PRIME_COAST_COMPENSATION_MS 300.0f                           // Grounds keep arriving roughly this long after the prime motor stops (measured ~380-410ms on logged sessions; kept conservative so the purge never under-delivers). The stop threshold is lowered by flow * this time so the configured amount is what actually lands, not what triggers the stop.

//------------------------------------------------------------------------------
// SCALE CALIBRATION AND SETTLING
//------------------------------------------------------------------------------
// Tare and settling behavior  
#define GRIND_SCALE_SETTLING_TOLERANCE_G 0.010f                           // Maximum standard deviation for settled reading. Used to determine if scale is settled. Increase value if you have a noisy load cell.

//------------------------------------------------------------------------------
// TIME MODE PULSE SETTINGS
//------------------------------------------------------------------------------
#define GRIND_TIME_PULSE_DURATION_MS 100                                        // Duration of additional pulses in time mode (milliseconds)



//------------------------------------------------------------------------------
// FLOW RATE PARAMETERS
//------------------------------------------------------------------------------
#define GRIND_FLOW_RATE_MIN_SANE_GPS 1.0f                                         // Minimum reasonable flow rate
#define GRIND_FLOW_RATE_MAX_SANE_GPS 3.0f                                         // Maximum reasonable steady-state flow rate
#define GRIND_PULSE_FLOW_RATE_FALLBACK_GPS 1.5f                                   // Fallback pulse flow rate when measured rate is invalid or too low
#define GRIND_PULSE_FLOW_MAX_SANE_GPS 4.0f                                        // Ceiling for EFFECTIVE pulse flow (yield incl. spin-down coast / productive ms). Legitimately exceeds the steady-state max - logged pulses ran up to ~1.4x steady flow - so pulse measurements and the seeded estimate clamp here, not at GRIND_FLOW_RATE_MAX_SANE_GPS

// Cross-session pulse gain learning. The first pulse of a session used to rely on
// the steady-state 95th-percentile flow alone, which under-predicts pulse yield
// (spin-down coast is unmodeled) - every logged first pulse over-delivered by
// 8-40%. The gain is the dimensionless ratio (effective pulse flow / steady-state
// estimate), learned as an EWMA and persisted to NVS ("pulse_gain"), so it
// survives bean changes (which shift absolute flow but not the ratio) and seeds
// the first pulse of every grind.
#define GRIND_PULSE_GAIN_DEFAULT 1.0f                                             // No correction until measurements arrive
#define GRIND_PULSE_GAIN_EWMA_ALPHA 0.2f                                          // Blend weight per accepted measurement (~5-grind memory; one outlier moves the estimate at most 20% of its clamped deviation)
#define GRIND_PULSE_GAIN_MIN 0.5f                                                 // Sample and estimate clamp - bounds outlier influence
#define GRIND_PULSE_GAIN_MAX 2.0f

//------------------------------------------------------------------------------
// TIMING CONSTRAINTS (Hardware-dependent)
//------------------------------------------------------------------------------
// Motor response latency - runtime configurable via auto-tune
#define GRIND_MOTOR_RESPONSE_LATENCY_DEFAULT_MS 50.0f                             // Safe default motor response latency
#define GRIND_MOTOR_MAX_PULSE_DURATION_MS 250.0f                                  // Maximum pulse duration above latency (latency + GRIND_MOTOR_MAX_PULSE_DURATION_MS)
#define GRIND_MOTOR_TEST_PULSE_MS 1000                                            // Menu motor test pulse length
#define GRIND_MOTOR_MAX_SUPPORTED_PULSE_MS 1000                                   // Longest pulse the RMT payload can hold (see Grinder static_asserts)

// Motor timing
#define GRIND_MOTOR_SETTLING_TIME_MS 200                                          // Motor vibration settling time
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

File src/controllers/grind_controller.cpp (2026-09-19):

#include "grind_controller.h"
#include "grind_events.h"
#include "pulse_flow_feedback.h"
#include "../hardware/circular_buffer_math/circular_buffer_math.h"
#include "../config/constants.h"
#include "../system/diagnostics_controller.h"
#include "../system/statistics_manager.h"
#include <Arduino.h>
#include <cstdarg>
#include <cstring>
#include <cmath>
#include <algorithm>

// UI event queue size
#define UI_EVENT_QUEUE_SIZE 10

// Flash operation queue size
#define FLASH_OP_QUEUE_SIZE 5

static constexpr float NO_WEIGHT_DELIVERED_THRESHOLD_G = 0.2f;

void GrindController::init(WeightSensor* lc, Grinder* gr, Preferences* prefs) {
    weight_sensor = lc;
    grinder = gr;
    preferences = prefs;
    phase = GrindPhase::IDLE;
    tolerance = GRIND_ACCURACY_TOLERANCE_G;
    current_profile_id = 0;
    force_measurement_log = false;
    target_time_ms = 0;
    time_grind_start_ms = 0;
    mode = GrindMode::WEIGHT;
    grinder_purge_mode_for_session = static_cast<GrinderPurgeMode>(GRIND_PURGE_MODE_DEFAULT);
    grinder_purge_amount_g_for_session = GRIND_PURGE_AMOUNT_DEFAULT_G;
    last_error_message[0] = '\0';
    last_session_result_ = GrindSessionResult::UNKNOWN;
    control_loop_paused_ = false;

    mechanical_anomaly_count_ = 0;
    last_mechanical_event_ms_ = 0;
    last_mechanical_weight_ = 0.0f;
    mechanical_monitor_initialized_ = false;

    // Initialize grind freshness tracking
    grinder_purged_since_boot = false;
    last_purge_runtime_ms = 0;
    if (preferences) {
        last_purge_runtime_ms = preferences->getULong64(PREF_KEY_LAST_GRIND_RUNTIME, 0);
    }

    // Set up grinder background indicator callback (if enabled)
    if (grinder) {
#if DEBUG_ENABLE_GRINDER_BACKGROUND_INDICATOR
        grinder->set_ui_event_callback([this](const GrindEventData& event_data) {
            // Forward grinder background events to our existing UI event queue
            if (event_data.event == UIGrindEvent::BACKGROUND_CHANGE) {
                this->emit_ui_event(event_data);
            }
        });
#else
        // Background indicator disabled - set empty callback
        grinder->set_ui_event_callback(nullptr);
#endif
    }
    
    // Initialize the grind logger
    if (!grind_logger.init(preferences)) {
        LOG_BLE("Warning: Grind logging disabled due to initialization failure\n");
    }
    
    // RealtimeController removed - functionality moved to FreeRTOS WeightSamplingTask and GrindControlTask
    
    // Initialize UI event system
    ui_event_callback = nullptr;
    ui_ready_for_setup = false;
    
    // Initialize thread-safe UI event queue
    ui_event_queue = xQueueCreate(UI_EVENT_QUEUE_SIZE, sizeof(GrindEventData));
    if (!ui_event_queue) {
        LOG_BLE("ERROR: Failed to create UI event queue\n");
    } else {
        LOG_BLE("UI event queue created successfully\n");
    }
    
    // Initialize thread-safe flash operation queue
    flash_op_queue = xQueueCreate(FLASH_OP_QUEUE_SIZE, sizeof(FlashOpRequest));
    if (!flash_op_queue) {
        LOG_BLE("ERROR: Failed to create flash operation queue\n");
    } else {
        LOG_BLE("Flash operation queue created successfully\n");
    }
    
    // Initialize thread-safe log message queue
    log_queue = xQueueCreate(LOG_QUEUE_SIZE, sizeof(LogMessage));
    if (!log_queue) {
        LOG_BLE("ERROR: Failed to create log message queue\n");
    } else {
        LOG_BLE("Log message queue created successfully\n");
    }

    strategy_context.controller = this;
    active_strategy = nullptr;

    // Load motor response latency from preferences
    load_motor_latency();
    load_pulse_gain();
}

void GrindController::start_grind(float target, uint32_t time_ms, GrindMode grind_mode) {
    LOG_BLE("[%lums CONTROLLER] start_grind() called with target=%.1fg, time=%lums, mode=%s\n",
            millis(), target, (unsigned long)time_ms, grind_mode == GrindMode::TIME ? "TIME" : "WEIGHT");
    if (!weight_sensor || !grinder) return;
    if (weight_sensor->has_hardware_fault()) {
        LOG_BLE("ERROR: Cannot start grind - load cell hardware fault detected (%d)\n",
                static_cast<int>(weight_sensor->get_hardware_fault()));
        return;
    }
    // A saturated load cell reports a constant weight, so weight-mode control has no
    // feedback: taring captures the rail, flow is never detected, and the grind would
    // run to the timeout while dispensing. Time mode is unaffected (no weight feedback).
    if (grind_mode == GrindMode::WEIGHT && weight_sensor->is_signal_saturated()) {
        LOG_BLE("ERROR: Cannot start weight-mode grind - load cell signal saturated. Check A+/A- signal wiring.\n");
        return;
    }

    target_weight = target;
    target_time_ms = time_ms;
    mode = grind_mode;

    // Read grinder purge settings from preferences (always run for weight mode)
    grinder_purge_mode_for_session = static_cast<GrinderPurgeMode>(GRIND_PURGE_MODE_DEFAULT);
    grinder_purge_amount_g_for_session = GRIND_PURGE_AMOUNT_DEFAULT_G;
    if (preferences) {
        int purge_mode_int = preferences->getInt(PREF_KEY_GRINDER_MODE, GRIND_PURGE_MODE_DEFAULT);
        grinder_purge_mode_for_session = static_cast<GrinderPurgeMode>(purge_mode_int);
        float configured_amount = preferences->getFloat(PREF_KEY_GRINDER_AMOUNT_G, GRIND_PURGE_AMOUNT_DEFAULT_G);
        configured_amount = std::clamp(configured_amount, GRIND_PURGE_AMOUNT_MIN_G, GRIND_PURGE_AMOUNT_MAX_G);
        grinder_purge_amount_g_for_session = configured_amount;
    }

    start_time = millis();
    pulse_attempts = 0;
    timeout_phase = GrindPhase::IDLE; // Initialize timeout phase
    timeout_pause_start = 0;
    timeout_offset_ms = 0;
    last_session_result_ = GrindSessionResult::UNKNOWN;
    // Load cell now runs at constant high speed - no mode switching needed
    
    
    grind_latency_ms = 0;
    predictive_end_weight = 0;
    final_weight = 0;
    motor_stop_target_weight = GRIND_UNDERSHOOT_TARGET_G; // Start with a safe default

    time_grind_start_ms = 0;

    flow_start_confirmed = false;

    // Initialize dynamic pulse algorithm variables
    pulse_flow_rate = 0.0f;
    pulse_flow_base = 0.0f;
    
    // Initialize loop counters
    current_phase_loop_count = 0;
    
    // Initialize measurement state tracking for logger
    last_logged_weight = 0.0f;
    last_logged_time = millis();
    force_measurement_log = false;

    // Reset UI acknowledgment flag for new grind
    ui_ready_for_setup = false;

    // Reset flash operation flag for new grind
    session_end_flash_queued = false;
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

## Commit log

2026-07-25 Add forward-shifted cup holder variant for a 43 mm cup base
    The cup sits far enough back that it contacts the rear wall of the grinder
    body, which loads the cup against something other than the scale and shows
    up as load-cell noise. This shifts the cradle 8 mm toward the screw holes
    and offers a pocket sized for a 43 mm cup base.
    Three STLs: pocket Ø43.50 (recommended, self-centring on the fillet ring),
    Ø44.00 (fallback for tighter-printing machines) and Ø45.33 (stock pocket,
    forward shift only).
    Screw holes, mount plate, side rails and overall height are unchanged --
    all 11,295 baseline triangles below the z=-167 freeze line are verbatim.
    The 2 mm backstop wall and 8.74 deg draft are p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
    [Cup holder (baseline export).step, Cup holder (baseline export).stl]
2026-07-25 feat: add error diagnostic when a cell is saturated
    [WeightSensor.cpp, grind_controller.cpp, hardware.h]
2026-07-25 feat: top-up pulses in weight mode with live weight, 0.1s time floor
    The "+" button on the completion screen now appears after every grind, not
    just timed ones. Each tap fires a fixed 100ms hardware-timed pulse with no
    re-tare and no purge, so a shot that landed at 17.8g can be nudged to 18.0g.
    TIME_ADDITIONAL_PULSE is held after the motor stops until the scale settles.
    That keeps the phase out of COMPLETED while grounds fall, so the displayed
    weight and arc track the pulse live, final_weight captures the full yield, and
    a second tap cannot land before the first is measured. The phase name is kept
    because phase_id ordinals are part of the on-flash log format.
    Also:
    - Clear timeout_offset_m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
    [grind_controller.cpp, user.h]
2026-07-25 perf: cut per-frame LVGL heap churn in the UI, fix style leak
    LVGL is configured with LV_USE_STDLIB_MALLOC = LV_STDLIB_CLIB, so every
    LVGL allocation lands in the shared internal DRAM heap. Several UI paths
    rewrote widget text and styles on every 60Hz frame, and neither
    lv_label_set_text() nor lv_obj_set_style_text_color() has a value-change
    early-out: each call is an unconditional free/malloc plus an invalidate.
    - Add set_label_text_if_changed() / set_label_text_color_if_changed()
    helpers and route set_label_text_int/_float through them, so all
    existing call sites compare before reallocating.
    - Refresh only the menu page that is on screen, at 4Hz instead of 60Hz,
    with ESP.getFreeHeap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
    [system.h]
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2026-07-26 fix: bound CircularBufferMath scratch buffers to the sampling poll rate
    [circular_buffer_math.cpp, system.h]
2026-07-26 fix: make motor pulses exact and deterministic
    [autotune_controller.cpp, grind_controller.cpp, grinder.cpp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]
2026-07-26 fix: preserve grind flow and calibration accuracy
    [WeightSensor.cpp, circular_buffer_math.cpp]
2026-07-26 fix: complete auto-tune cancellation and correct failure reporting
    Cancelling auto-tune only set a deferred flag, but AutoTuneController::update()
    is reached solely from UIState::AUTOTUNING and the UI leaves that state on the
    same call stack. The flag was never serviced, so the controller stayed running
    and the log file stayed open - every later start() was rejected as "already
    running" until reboot. cancel() now completes the run synchronously.
    Also report the retained latency instead of the default on verification
    failure, matching what is actually kept.
    [autotune_controller.cpp]
2026-07-26 fix: detect motor pulse completion without polling the RMT driver
    Polling rmt_tx_wait_all_done() emitted an ESP_LOGE "flush timeout" on every
    unfinished poll - roughly 27 lines per 550ms correction pulse at the 20ms
    control interval, and hundreds per auto-tune run. Completion now comes from
    the RMT transmit-done callback via an atomic flag, so the control loop makes
    no driver call at all.
    Spread pulse time evenly across symbol halves so no half is zero-length.
    Termination is then handled by the driver's end-of-transmission marker and the
    configured eot_level, rather than relying on a zero-duration entry inside the
    payload acting as an end marker.
    Key the RMT payload capacity off a dedicate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
    [autotune_controller.cpp, grind_control.h, grind_controller.cpp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]
2026-07-26 fix: report tare and calibration failures to the user
    A failed tare or calibration correctly kept the previous value and skipped the
    success transition, but the overlay hid itself either way - so the wizard sat
    on the same step with no explanation and only a serial log recorded why.
    Add a self-dismissing notice to BlockingOperationOverlay and an on_failure
    callback to the tare and calibration wrappers, and use them from the
    calibration wizard and the menu scale page.
    Also close the tare disarm race: the sampling task now claims the request with
    a compare-exchange, so a caller that times out cannot have the zero point moved
    underneath it afterwards. Calibration decides whether settling time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
    [WeightSensor.cpp, system.h]
2026-07-30 fix: keep the BLE stack alive across Bluetooth toggles
    Bluedroid rebuilds an empty GATT table on every deinit()/init() cycle
    while the Arduino BLE wrapper keeps its server and service objects, so
    re-creating the services on each enable served duplicate or missing
    characteristics and broke UUID lookups in clients. The stack, GATT
    table and advertising payload are now built once; toggling Bluetooth
    only starts and stops advertising, force-disconnecting any client on
    disable. enable() is also guarded against reentrancy so overlapping
    bootup and menu enables can no longer duplicate the GATT setup.
    Claude-Session: https://claude.ai/code/session_01QZJxZYCA3L7xuGqjzbG8Fx
2026-07-30 feat: pull device health with grind data and surface it in the dashboard
    The analyze command now captures system info and the diagnostics report
    over the same BLE connection as the session export, stores them in a
    device_reports table beside the grind data, and the Streamlit report
    gains a Device Health view showing firmware, memory, task performance,
    hardware status and the raw diagnostics report with a download button.
    Failures degrade gracefully: a partial pull still opens the dashboard.
    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
2026-07-31 fix: deliver BLE data exports reliably with acknowledged, retried chunks
    [bluetooth.h]
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2026-07-31 feat: record every grind by default with space-based retention and BLE time sync
    - Grind logging preference now defaults to ON; the dashboard and health
    snapshot expose its state so silent data loss is visible
    - Session retention is space-based: keep sessions until LittleFS free space
    drops below a 256KB reserve (oldest purged first, 250-file safety cap)
    instead of a fixed 10-session limit; BLE file list cap raised to match
    - New sysinfo timesync characteristic: clients write the wall clock +
    timezone on every connect (Python tool does this automatically); sessions
    started after a sync carry real Unix epochs in session_timestamp with no
    schema change (parsers distinguish epoch fr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
    [bluetooth.h, grind_logging.cpp, grind_logging.h]
2026-07-31 feat: add compare and trends views with wear odometer to web analytics
    - Compare: overlay up to 10 sessions' weight curves aligned at grind start,
    newest grind brightest on a sequential blue ramp, shared target line,
    optional flow traces, checkbox selection from a newest-first table
    - Trends: error/flow-rate/latency/pulse-count drift across logged sessions
    (burr-wear early-warning signals) plus a lifetime odometer row sourced
    from the device's statistics so unlogged grinds still count
    - Warning banner when grind logging is off on the device; Device Health
    shows logging state, session storage usage and clock sync status
    - Session timestamps render as real dates once the device clock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
2026-07-31 docs: refresh analytics screenshots with the new web dashboard UI
    Replace the old Streamlit dashboard screenshot with captures of the web
    flasher's Analytics tab (single-session, compare, trends with burr-wear
    odometer, device health) and correct the docs to reflect that session
    logging is now on by default with space-based retention.
2026-07-31 fix: recover cleanly from an interrupted BLE firmware update
    Abort a transfer that goes quiet for 30s while the link is still up, so a
    dead client no longer leaves the hardware tasks suspended indefinitely.
    Leave the OTA progress screen when an update ends without a restart and
    show the acknowledgeable failure screen instead of freezing at the last
    percentage.
    [bluetooth.h, ota_handler.cpp]
2026-07-31 feat: sync the clock over WiFi with on-device DST rules
    WiFi credentials are provisioned over BLE from the web flasher's new WiFi
    Setup tab and stored in NVS. A duty-cycled WifiService syncs the clock via
    SNTP at boot (surviving power loss) and daily after, with backoff on
    failure; the radio stays off otherwise and attempts never overlap a grind,
    OTA, or BLE data export. The flasher derives a POSIX TZ rule from the
    browser's own DST knowledge (tz-posix.js, no zone table to go stale) and
    the firmware applies it via setenv("TZ")/tzset(), so daylight-saving
    transitions happen locally with no network. SNTP is driven through
    esp_sntp directly because Arduino's configTime() overwrites TZ with UTC.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
    [bluetooth.h, main.cpp]
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2026-07-31 fix: stop the stall watchdog and disconnects from killing an OTA mid-apply
    Applying a received patch blocks for 30-90s (partition erase, heatshrink
    decompress, 2.2MB write). The stall watchdog only sees that chunks stopped
    arriving, so it "aborted" every long apply 30s in and resumed the suspended
    hardware tasks while flash cache was being toggled - which is how a web OTA
    could reach 100%, reboot, and still be running the old firmware. Web OTAs
    hit this deterministically (their from-empty patches decompress the whole
    image); Python delta applies mostly squeaked under the window.
    The apply now runs on the bluetooth task instead of the NimBLE host task
    (deferred END command, same pattern as t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
    [ota_handler.cpp, system.h]
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2026-07-31 feat: tighten status icon spacing and add a 12/24-hour clock preference
    The WiFi, warning and BLE icons now sit in a right-aligned flex row, so the
    visible ones stay shoulder to shoulder instead of leaving a gap where a hidden
    icon used to be.
    The wall clock renders as AM/PM by default, with a 24-Hour toggle under
    Menu -> Settings -> Display persisted in the "clock" NVS namespace. Both the
    ready screen corner clock and the System Info row follow the preference.
    [main.cpp]
2026-07-31 refactor: streamline web flasher device strip and install flows
    - Replace the grinder hero/card with a compact device status strip
    - Remove redundant firmware selection status messages
    - Tighten installation and WiFi panel copy
2026-07-31 fix: log PURGE_CONFIRM and PREDICTIVE as separate grind events
    continue_from_purge() switched phases with the default empty loop_data,
    so the PURGE_CONFIRM event was never closed and the whole predictive
    phase was logged under phase_id PURGE_CONFIRM with a stale timestamp
    and start weight. Pass real loop_data so both events log correctly.
    [grind_controller.cpp]
2026-07-31 feat: close the loop on correction pulse flow estimates
    The pulse duration model used a flow rate sampled once at the end of the
    PREDICTIVE phase and never checked it against what pulses actually
    delivered, so any estimation error persisted for every pulse of the
    session (logged pulses over-delivered by 8-25%). Each pulse's settled
    yield now re-derives the flow estimate for the next pulse, rejected when
    outside the existing sanity bounds. Pure logic lives in
    pulse_flow_feedback.h with a host-side regression test.
    [weight_grind_strategy.cpp]
2026-07-31 fix: coast-compensate the prime/purge stop threshold
    The prime phase stopped the motor once the scale read the configured
    amount, but grounds keep arriving for ~400ms after motor-off, so a 1.0g
    purge landed ~1.9g (logged sessions). Lower the stop threshold by
    flow * GRIND_PRIME_COAST_COMPENSATION_MS (300ms, conservative) so the
    configured amount is approximately what actually lands.
    [grind_control.h, grind_controller.cpp]
2026-07-31 fix: count overshoot grinds in lifetime statistics
    Overshoots are delivered shots; excluding them hid high-side misses and
    biased avg accuracy optimistic (a shot 0.04g over was excluded while
    equivalent undershoots counted). Timeouts stay excluded.
    [grind_logging.cpp]
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2026-07-31 feat: learn pulse gain across sessions to fix first-pulse overshoot
    Every logged first pulse over-delivered by 8-40% because the steady-state
    95th-percentile flow under-predicts pulse yield (spin-down coast is
    unmodeled) and in-session feedback can only correct from the second pulse
    on - but sessions typically need exactly one pulse. Learn the
    measured-vs-predicted flow ratio as a clamped EWMA (alpha 0.2, bounds
    0.5-2.0), persist it in NVS, and seed the first pulse of every grind
    with it. Also raise the pulse-flow acceptance ceiling to 4.0 g/s:
    effective pulse flow legitimately exceeds the steady-state sane maximum,
    which was silently rejecting valid measurements at the 3.0 boundary.
    [grind_control.h, grind_controller.cpp, weight_grind_strategy.cpp]
2026-08-01 fix: stage OTA patches in PSRAM so large BLE transfers survive
    Flash erases/writes on the BLE receive path stall the radio long enough
    to drop the connection partway through large transfers - full updates
    reliably died mid-flight while a flash-free stream of the same size ran
    clean. The whole patch is now held in PSRAM and flash is untouched until
    the transfer completes (16 KB-batch streaming fallback if the PSRAM
    allocation fails). Verified with a 1.6 MB full update over BLE.
    Also stop flashing the "Update Failed" screen during the pre-reboot
    window of a successful apply - the UI treated "OTA no longer active" as
    a failure even when the device was about to restart into the new image.
    [ota_handler.cpp]
2026-08-01 fix: generate BLE delta updates against the correct base image
    Every CI release compiled as Build #1 (.build_number is gitignored), so
    release-flashed devices matched the unrelated local firmware_cache
    build_001.bin and delta patches were diffed against bytes not on the
    device - guaranteed apply failure. Release builds now get unique numbers
    seeded from the commit count (offset +100000), the tool never treats
    release build numbers as local cache entries, and when no cached base
    exists it fetches the published release binary matching the device's
    firmware version (a release-flashed device's partition is byte-identical
    to the published binary).
    Also harden the upload path: retry transient chu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
2026-08-01 fix: report real OTA outcomes in the web flasher
    The web flasher treated timeouts and disconnects after the END command
    as success, hiding real failures. It now waits for the device's own
    success/error status through the 30-90 s apply phase; if the link drops
    without a verdict it reconnects after the reboot and verifies the
    running firmware version instead of assuming success. Chunk writes retry
    transient failures, the full-update flag is sent correctly (web-ota.bin
    is a from-empty patch), and the bogus expected build number "1" - which
    could only produce false post-boot failure popups - is no longer sent.
2026-08-01 feat: harden BLE OTA with boot guard, base hash check, patch CRC and outcome log
    Four safety nets around firmware updates:
    - Boot-loop guard: three consecutive crash resets (panic/watchdog only -
    power cycling never counts) revert to the other OTA slot when it holds
    a valid image, so a bad update auto-recovers instead of bricking the
    device until USB. Decision logic is pure and host-tested.
    - Running-image hash: the firmware serves the running app's SHA-256 over
    BLE and the Python tool refuses any delta base that doesn't match it,
    falling back to a full update - wrong-base deltas are now structurally
    impossible rather than prevented by convention.
    - Patch checksum: both clients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
    [bluetooth.h, main.cpp]
2026-08-01 test: add boot-guard rollback drill behind a debug flag
    DEBUG_BOOT_GUARD_DRILL builds a firmware that deliberately panics ~5s
    after boot - after the guard has counted, before the healthy mark - so
    three crash cycles exercise the crash rollback on real hardware. An
    independent NVS counter disarms the drill after 4 boots, so even a
    guard failure leaves the device alive and OTA-rescuable.
    Drill executed on hardware: 3 panics, rollback fired on the 4th boot,
    device reverted from the drill build to the previous slot in ~35s, and
    diagnostics recorded "crash loop on v1.6.0-rc.5 #84 -> reverted to
    'ota_0' slot". The drill build was removed from the firmware cache.
    [debug.h, main.cpp]
2026-08-01 feat: pin the patch toolchain with a compat test and hash-verify downloads
    Two supply-chain guards for OTA updates:
    - detools/heatshrink2 are pinned exactly (venv, release CI, test CI) and
    test_patch_compat.cpp enforces the pin's validity: the harness
    generates a patch with the installed Python detools at test time and
    the real C decoder from components/detools must reconstruct the
    target byte-for-byte. A patch-format drift now fails on the host
    instead of breaking every field update.
    - Releases publish a SHA-256 manifest of their binaries. The CLI
    verifies fetched delta bases against it and the web flasher verifies
    its downloaded OTA binary via WebCrypto before flashing; rele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
2026-08-01 fix: hold the BLE link during long web flasher operations
    The shared session releases the connection after 30s idle, but nothing
    claimed it during long operations. Any concurrent flow calling release()
    - typically the device strip's background snapshot refresh - armed that
    timer, so a firmware upload died partway through with "GATT Server is
    disconnected". The device recorded it as "aborted: client disconnected
    mid-transfer".
    Adds a nesting hold()/releaseHold() lease: while any holder is active,
    release() is a no-op and the idle timer stays disarmed. The firmware
    upload, the diagnostics stream and the grind-data export now hold the
    link for their duration. An explicit disconnect clears outs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
2026-08-01 feat: keep Bluetooth available whenever the grinder is powered on
    BLE no longer disables itself after an idle period, so the web flasher
    and CLI can connect at any time without a trip to the device menu. The
    Enabled toggle still turns the radio off until the next reboot, and the
    Startup toggle remains the durable off switch.
    Advertising stays at the stack default rate: slowing it to cut radio duty
    made the grinder unreliable to discover and connect to at realistic signal
    strength, and load-cell noise measures the same either way.
    Also removes the CPU-frequency "power mode" path, which switched between
    240MHz and 240MHz, and an unused OTA time-remaining estimate that derived
    its elapsed tim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
    [bluetooth.h, ota_handler.cpp]
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2026-08-02 feat: cloud source and backfill in the Analytics tab
    - IndexedDB records re-keyed by sha256 of the raw session file (v2 schema);
    BLE pulls keep the verbatim device bytes and hash them client-side
    - Cloud bar: create store, sync from cloud, back up local sessions,
    read-only dashboard share links (#store=id:view_key), disconnect/delete
    - Cloud sync pulls only missing blobs and parses them with the shared
    parser into the same store the BLE path fills — every view renders
    identically from either source; BLE pulls auto-backfill to the store
    and push a compact health observation
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2026-08-02 feat(firmware): brew entry screen, active bean, and grind advice
    While a bean is provisioned (BLE push from the dashboard or the cloud
    config fetch — the server is the source of truth both channels carry),
    every logged grind exits its completion screen into a brew entry screen:
    shot yield pre-set to dose x ratio (including top-up pulses), 0.1 g jog
    with the edit screen's click/hold grammar, a colored deviation line
    (fast/slow/on target), DONE, and a corner skip. It holds 15 minutes,
    auto-start-on-cup stays armed underneath, and a new grind supersedes an
    unanswered prompt. No bean, no change to the flow.
    DONE queues the record under /brews on LittleFS (deliberately not
    /sessions) and pulls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
    [bluetooth.h, cloud_sync.cpp, grind_logging.cpp]
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2026-08-04 feat(ui): two-step brew entry, and a bag chip that clears the grind button
    The advice/bag chip was anchored to the ready container's bottom edge —
    LV_PCT(80) = 364 — while the grind button, a sibling of the whole screen,
    starts at 346. It drew 16px underneath it. Anchor off the button's keep-out
    instead, and cap the chip width so a longer verdict can't reach the bezels.
    Brew entry moves to the edit screen's anatomy: value, full-width jog row,
    commit row. The corner X sat on top of the status icon row in every case —
    it owns the top-right 90x48 — so skip becomes half of a two-button commit
    row. Edge-mounted jog buttons left the value ~148px, and six characters at
    montserrat_48 measur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
    [cloud_sync.cpp, user.h]
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2026-08-05 feat(firmware): record why the grinder rebooted, and keep the shot log across it
    esp_reset_reason() separates a brownout from a firmware crash, and this
    board exposes no serial port, so that answer was being logged into the
    void. A ring of the last 8 boots now persists to NVS - reset kind, build,
    and the wall-clock start time, stamped once the clock first syncs -
    alongside an RTC_NOINIT black box holding what the device was doing
    milliseconds before it died: UI state, grind phase, cloud sync phase,
    free internal heap. RTC RAM survives panic, watchdog and brownout resets
    at no flash cost, and a checksum rejects the debris left after a true
    power-on. Both print under [BOOT HISTORY] in the diag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
    [cloud_sync.cpp]
2026-08-17 fix(wifi): keep the radio off the boot current draw and away from the motor
    The radio now comes up at exactly two moments, neither overlapping another
    load on the supply: a CLOCK_ONLY window 60s after boot (was 5s, with the
    uploader's TLS handshake riding it - the exact signature of the 2026-08-06/07
    brownouts), and a CLOUD_SYNC window 30 minutes after the last grind or brew
    record (was 15s after a grind). Nothing is periodic: a stale clock is
    refreshed inside a cloud window that is already open.
    Retries only ever owe the clock: a window torn down for a grind/OTA/export
    restarts the 30-minute quiet delay on the spot, an aborted cloud window
    schedules no retry at all, and pending cloud work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
    [cloud_sync.cpp, wifi_service.h]
2026-09-06 fix: cap wifi power
    [wifi_service.h]
2026-09-19 fix: sensor freeze doesnt kill grind
    [WeightSensor.cpp, hx711_driver.cpp]
2026-09-19 fix: abort with Err: no scale when the load cell stops delivering samples mid-grind
    [WeightSensor.cpp, grind_control.h, grind_controller.cpp]
